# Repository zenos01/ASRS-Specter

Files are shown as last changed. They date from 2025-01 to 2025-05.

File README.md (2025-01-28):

# Fiber Optic FPV System

A **DIY Fiber Optic-enabled FPV video and control system** designed for affordable, high-performance drone operation. This system uses off-the-shelf components to deliver interference-free communication and advanced features at a cost of around **$300**.

## Key Features
- **Fiber Optic Communication**: Reliable and interference-free in challenging environments.
- **Customizable and Open Source**: Fully programmable, allowing for custom OSD elements, unique arming methods, and feature expansion.
- **High-Performance Video**:
  - Supports **1600x900 at 60fps** and **720p at 120fps**.
- **Advanced Capabilities**:
  - Real-time trajectory estimation for precise object dropping or landings.
  - Multi-camera support for enhanced situational awareness.
  - Ground station processing for greater computational power and flexibility.

## About the Project
This project aims to provide an affordable, flexible, and customizable alternative to traditional FPV systems. While still a prototype, it’s open to collaboration and feedback to refine and expand its capabilities.

## Getting Started
The **hardware guide** and **software guide** are currently a work in progress, but the basic setup will be updated soon. Stay tuned for detailed instructions!

## Contributing
Contributions are welcome! You can:
- Report issues via [GitHub Issues](link-to-issues).
- Suggest features or improvements.
- Submit pull requests to help refine the project.

---

Thank you.

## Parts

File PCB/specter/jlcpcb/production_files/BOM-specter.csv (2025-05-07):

Comment | Designator | Footprint | LCSC | Quantity
1K | R17,R19,R23 | R_0402_1005Metric | C11702 | 3
100uF | C14 | CP_EIA-7343-31_Kemet-D | C122321 | 1
10uF | C5,C7 | C_1206_3216Metric_Pad1.33x1.80mm_HandSolder | C13585 | 2
Bus_M.2_Socket_M | J3 | M.2 M Key socket | C1509730 | 1
100n | C1,C17,C2,C23 | C_0402_1005Metric | C1525 | 4
4.7nF | C18 | C_0402_1005Metric | C1538 | 1
10uF | C11,C12,C13,C15,C16,C19,C20,C21,C22,C8 | C_0805_2012Metric | C15850 | 10
SM04B-SRSS-TB_LF__SN_ | J22,J24,J25,J26 | JST_SM04B-SRSS-TB_LF__SN_ | C160404 | 4
1K | R2,R3,R5,R7,R8,R9 | R_0805_2012Metric_Pad1.20x1.40mm_HandSolder | C17513 | 6
SKQGAFE010 | S1 | SW_SKQGAFE010 | C202424 | 1
AP3441SHE-7B | U9 | DFN-8-1EP_2x2mm_P0.5mm_EP1.05x1.75mm | C2070918 | 1
AP2553W6 | U8 | SOT-23-6 | C212302 | 1
2.2uH | L1 | L_Bourns_SRP5030CC | C22404330 | 1
LED RED | D7,D8 | LED_0603_1608Metric | C2290 | 2
LED | D1,D2,D5,D6,D9 | LED_0805_2012Metric_Pad1.15x1.40mm_HandSolder | C2297 | 5
RT9742GGJ5 | U3 | SOT-23-5 | C250547 | 1
100K | 1% | R20 | R_0402_1005Metric | C25741 | 1
10K | 1% | R21 | R_0402_1005Metric | C25744 | 1
15K | R18 | R_0402_1005Metric | C25756 | 1
2.2K 1% | R1,R12,R13,R14,R22 | R_0402_1005Metric | C25879 | 5
ASEK-32.768KHZ-L-R-T | U10 | Crystal_SMD_3225-4Pin_3.2x2.5mm | C2650753 | 1
1uF | C3,C9 | C_0805_2012Metric_Pad1.18x1.45mm_HandSolder | C28323 | 2
LED | D3,D4 | LED_0805_2012Metric_Pad1.15x1.40mm_HandSolder | C34499 | 2
DF40C-100DS-0.4V_51_ | J6,J9 | HIROSE_DF40C-100DS-0.4V_51_ | C3642394 | 2
Micro_SD_Card_Det2 | J2 | SDCARD_MOLEX_503398-1892 | C428492 | 1
100nF | C4,C6 | C_0805_2012Metric_Pad1.18x1.45mm_HandSolder | C49678 | 2
74LVC1G07_copy | U7 | SOT-353_SC-70-5 | C5138996 | 1
USB_C_Receptacle_USB2.0_16P | J1 | USB_C_Receptacle_GCT_USB4105-xx-A_16P_TopMnt_Horizontal | C5187472 | 1
Conn_01x22_Socket | J4,J5 | Hirose_FH12-22S-0.5SH_1x22-1MP_P0.50mm_Horizontal | C597981 | 2
FT232RL | U1,U2 | SSOP-28_5.3x10.2mm_P0.65mm | C8690 | 2
SM06B-SRSS-TB_LF__SN_ | J27,J28,J29,J30 | JST_SM06B-SRSS-TB_LF__SN_ | C9900025724 | 4

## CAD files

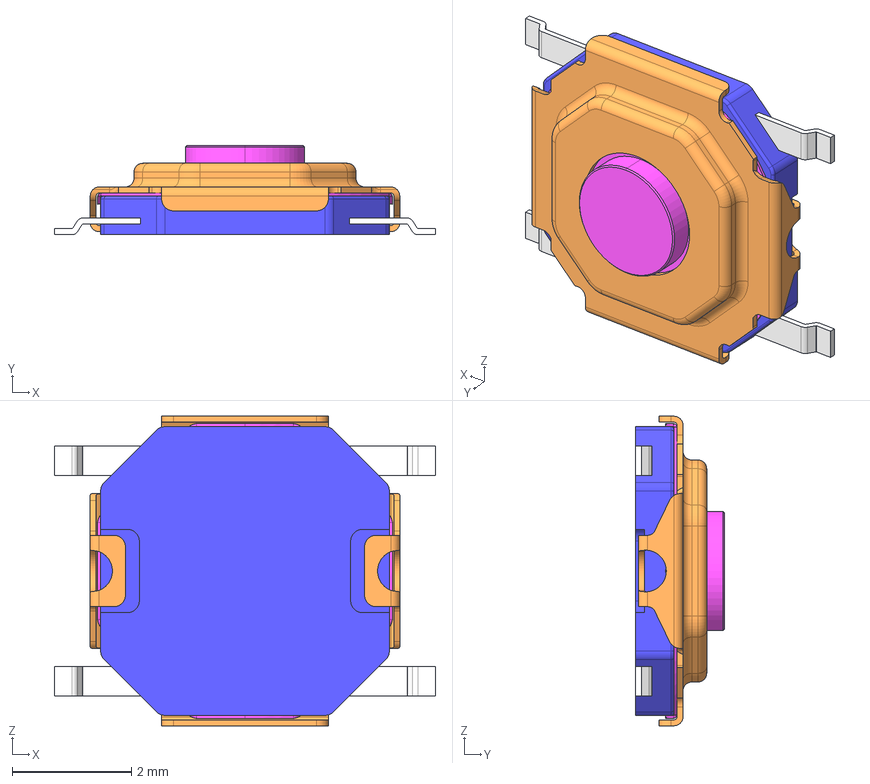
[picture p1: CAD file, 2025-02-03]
PCB/footprints/SKQGAFE010/SKQGAFE010.step
6.40 x 1.50 x 5.20 mm

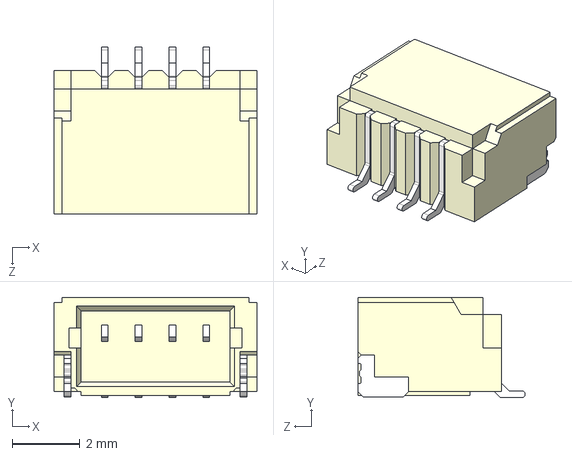
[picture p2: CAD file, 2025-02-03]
PCB/footprints/SM04B-SRSS-TB_LF__SN_/SM04B-SRSS-TB(LF)(SN)--3DModel-STEP-269445.STEP
6.00 x 2.96 x 4.95 mm

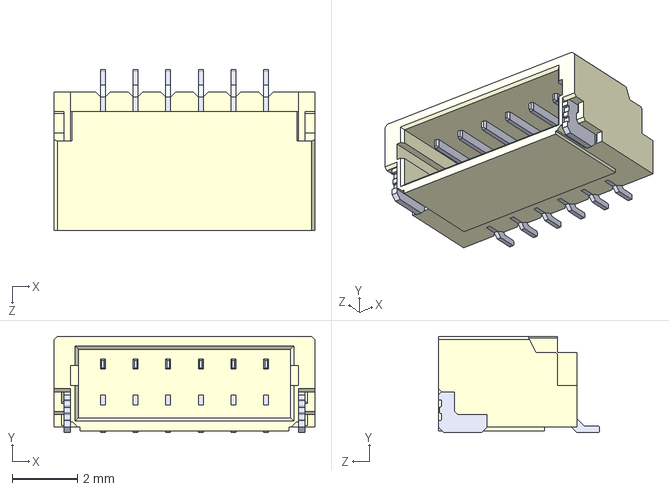
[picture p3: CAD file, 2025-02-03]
PCB/footprints/SM06B-SRSS-TB_LF__SN_/SM06B-SRSS-TB_LF__SN_.step
8.00 x 2.95 x 4.95 mm

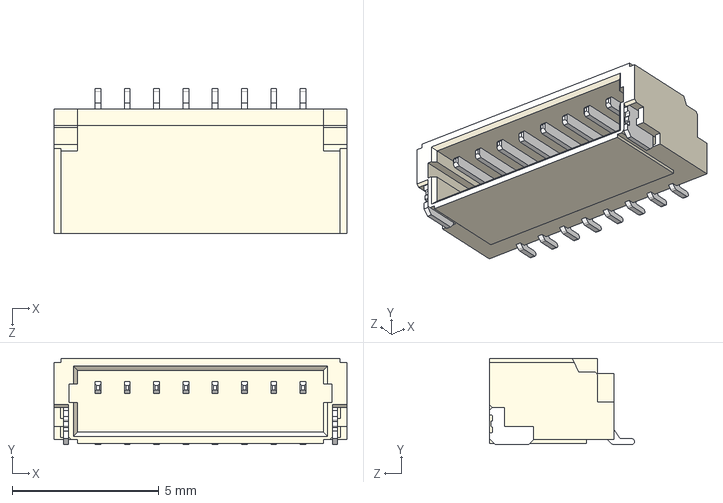
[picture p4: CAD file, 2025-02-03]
PCB/footprints/SM08B-SRSS-TB_LF__SN_/SM08B-SRSS-TB_LF__SN_.step
10.00 x 2.95 x 4.95 mm

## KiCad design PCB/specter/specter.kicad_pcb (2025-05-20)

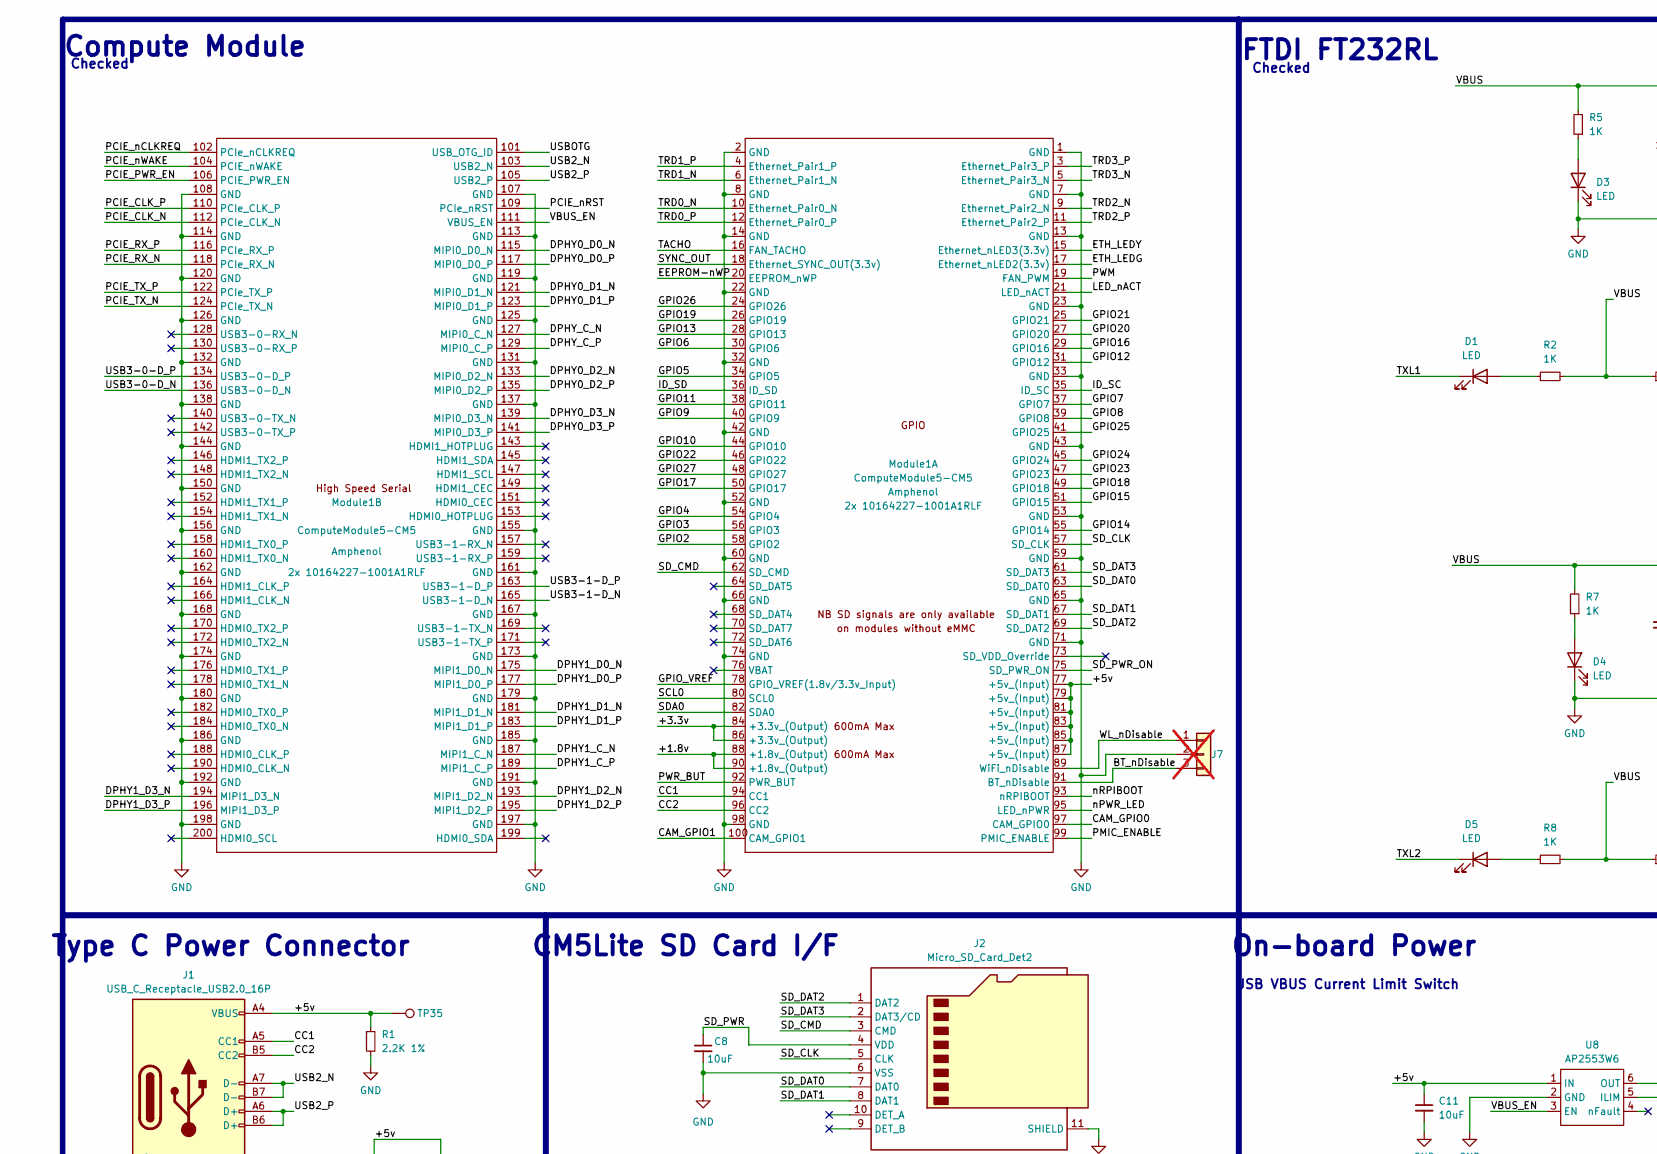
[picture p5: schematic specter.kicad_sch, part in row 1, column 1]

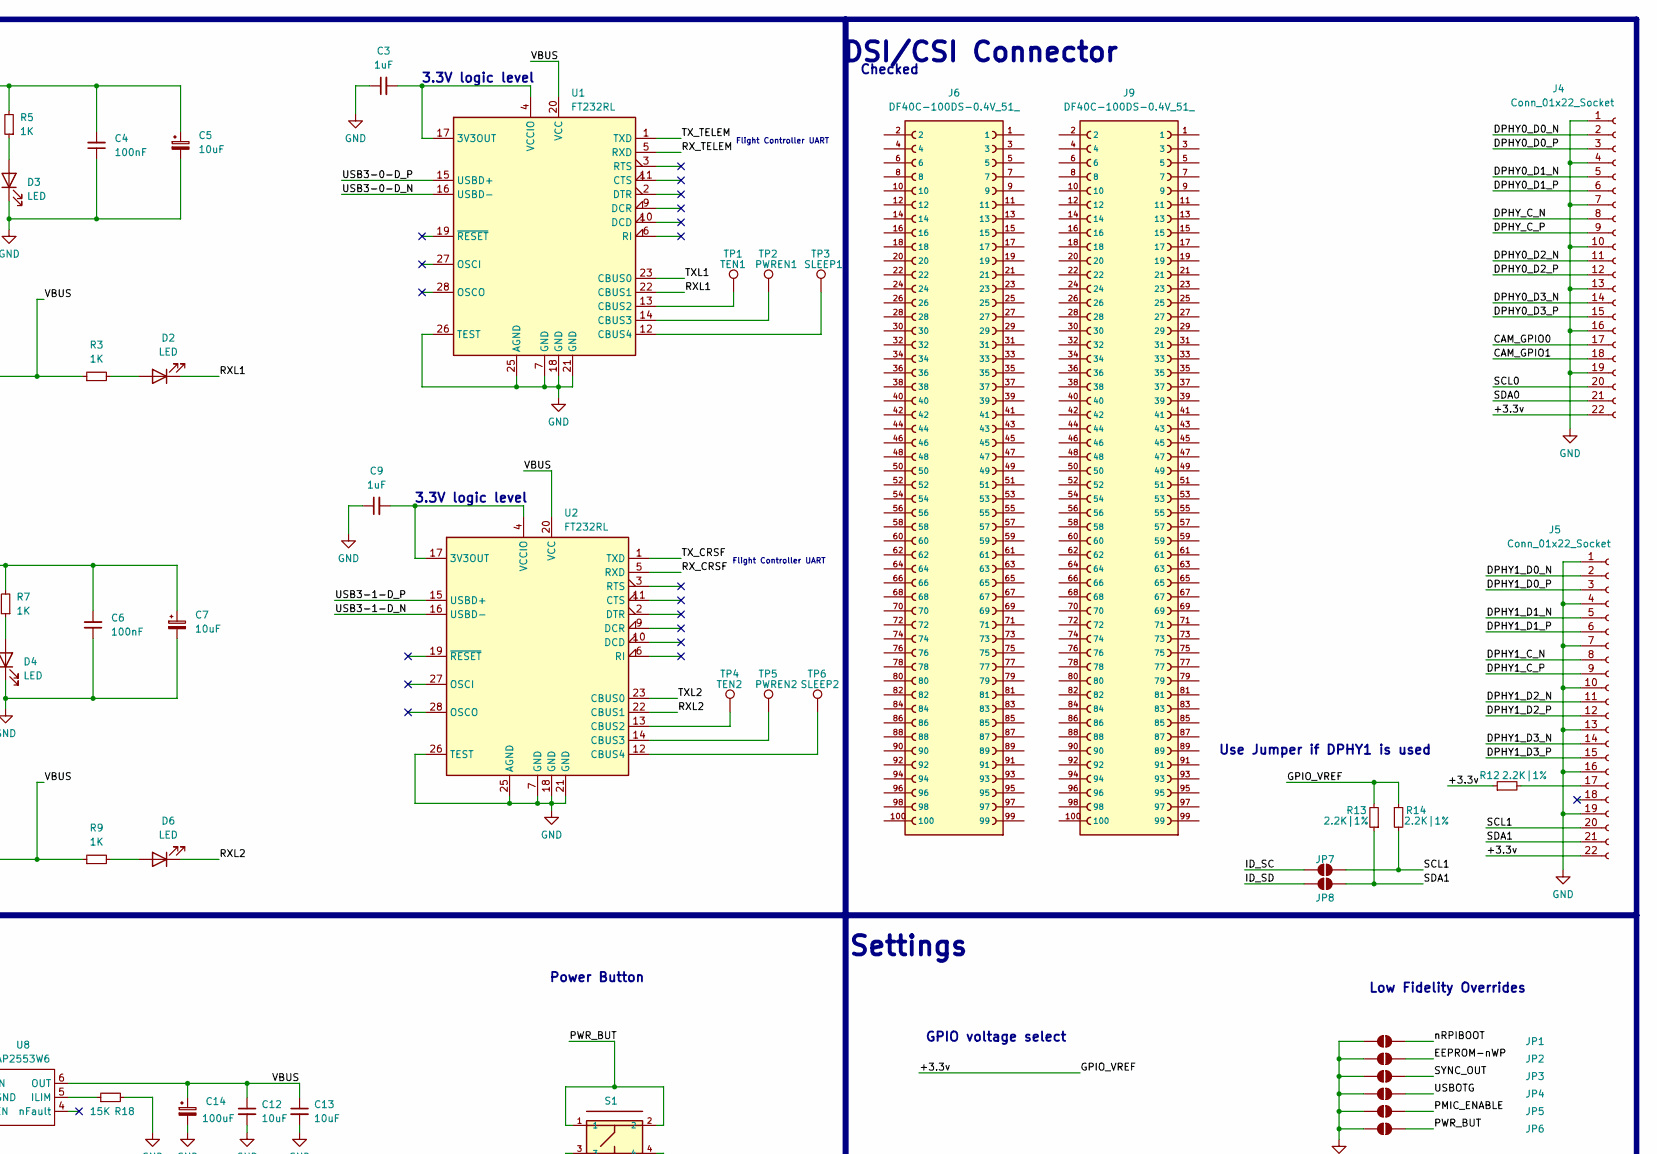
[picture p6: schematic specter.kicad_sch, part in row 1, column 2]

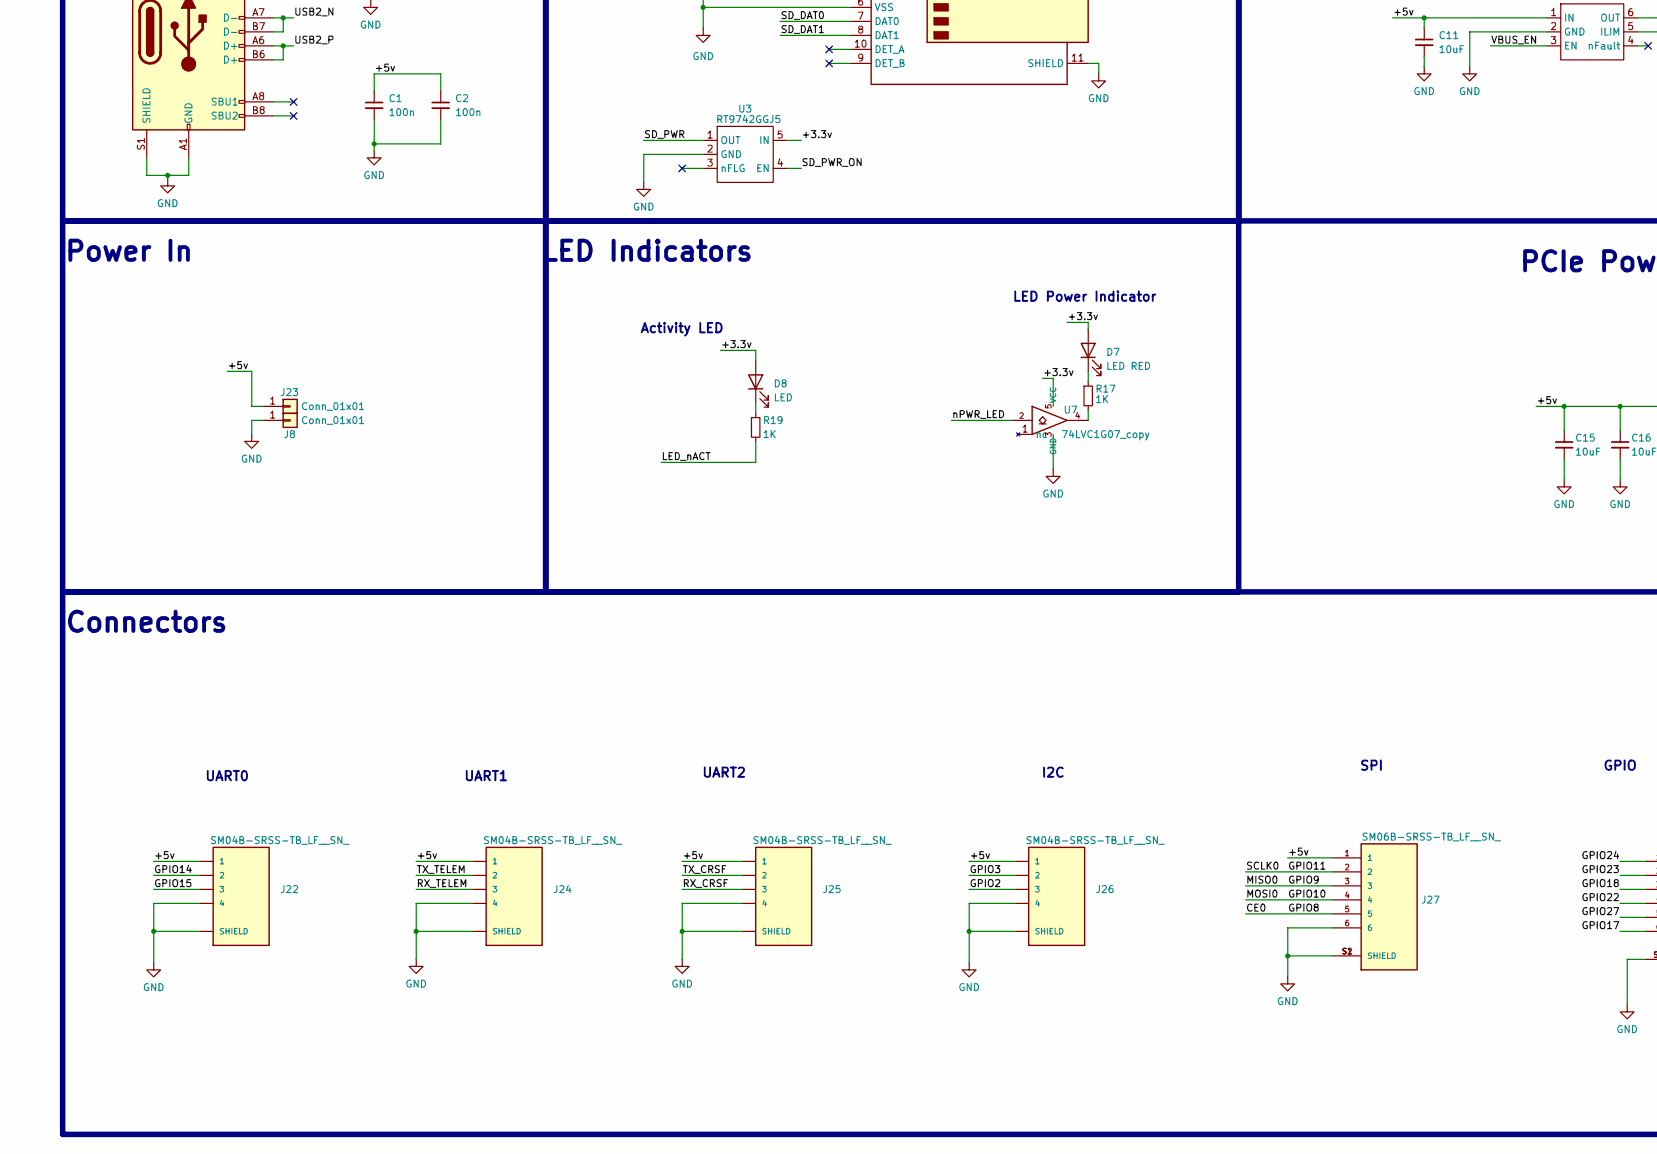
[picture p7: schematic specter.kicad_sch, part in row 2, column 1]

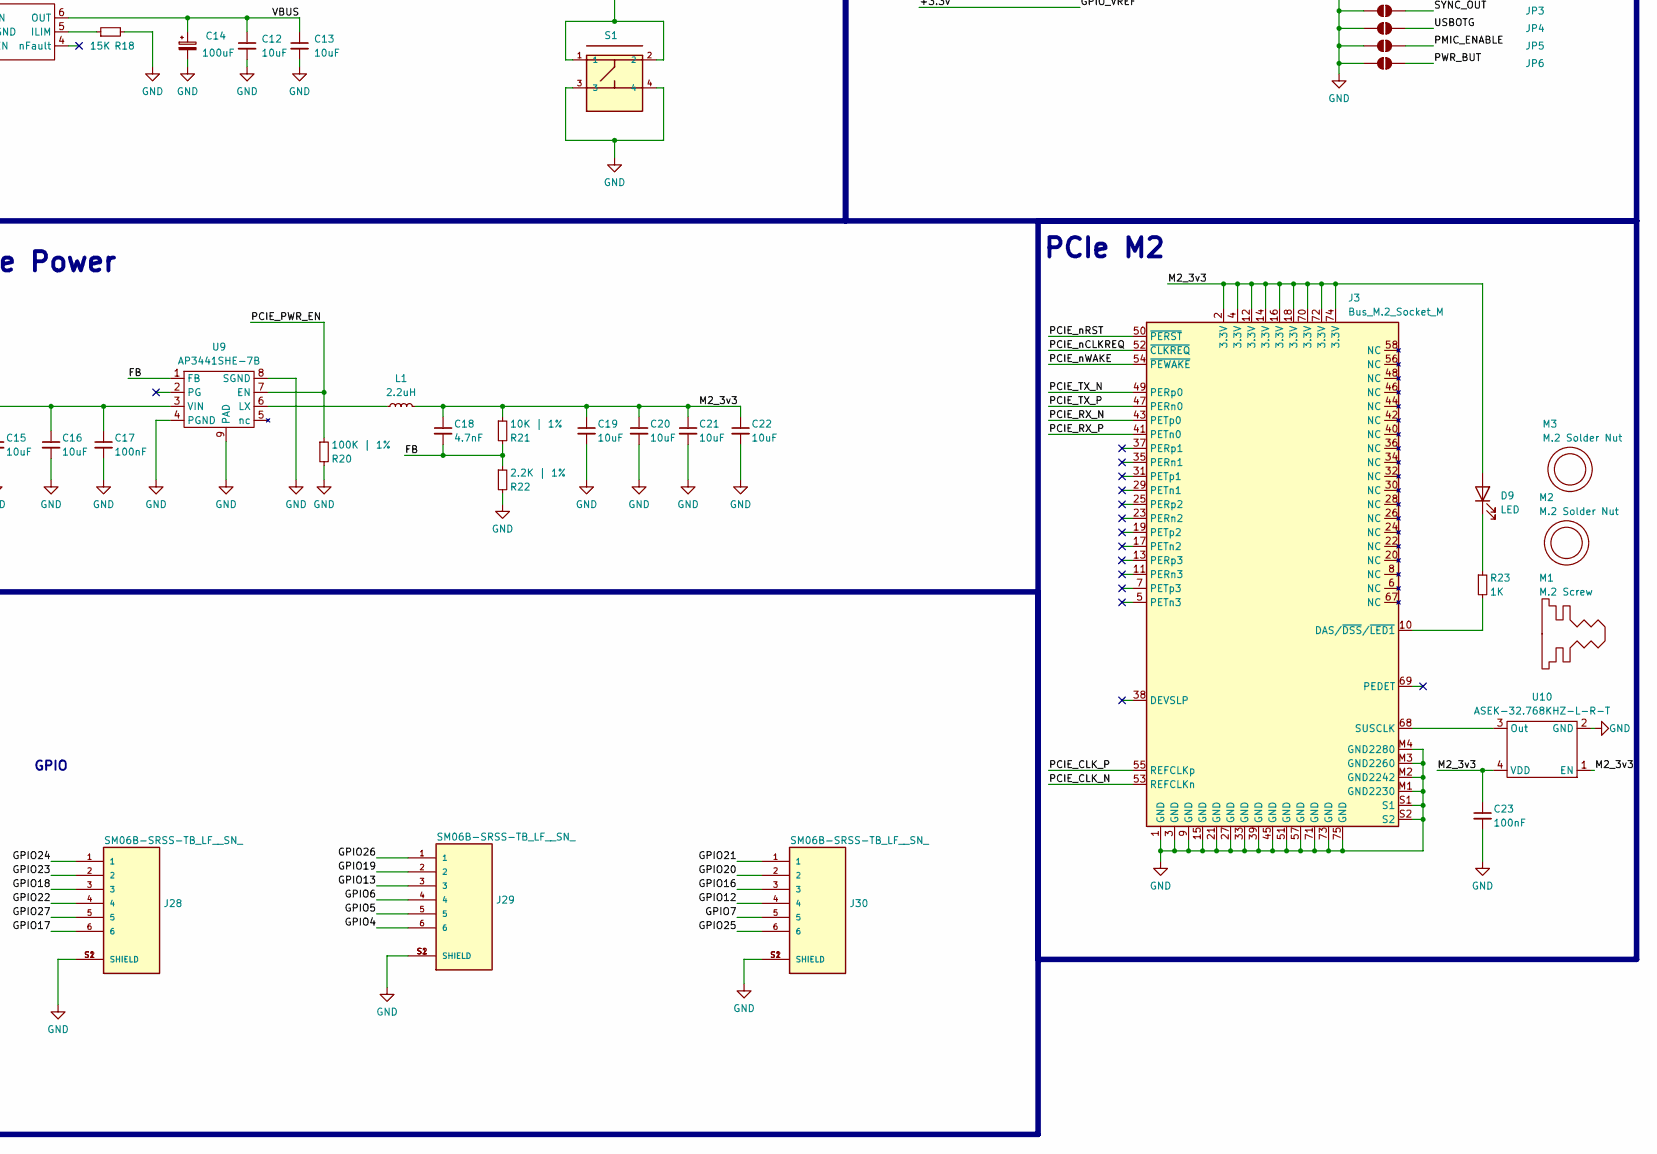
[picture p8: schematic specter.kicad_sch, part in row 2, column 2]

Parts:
C1, C2: 100n; C_0402_1005Metric
C3, C9: 1uF; C_0805_2012Metric_Pad1.18x1.45mm_HandSolder
C4, C6: 100nF; C_0805_2012Metric_Pad1.18x1.45mm_HandSolder
C5, C7: 10uF; C_1206_3216Metric_Pad1.33x1.80mm_HandSolder
C8, C11, C12, C13, C15, C16, C19, C20, C21, C22: 10uF; C_0805_2012Metric
C14: 100uF; CP_EIA-7343-31_Kemet-D
C17, C23: 100nF; C_0402_1005Metric
C18: 4.7nF; C_0402_1005Metric
D1, D2, D3, D4, D5, D6, D9: LED; LED_0805_2012Metric_Pad1.15x1.40mm_HandSolder
D7: LED RED; LED_0603_1608Metric
D8: LED; LED_0603_1608Metric
J1: USB_C_Receptacle_USB2.0_16P; USB_C_Receptacle_GCT_USB4105-xx-A_16P_TopMnt_Horizontal
J2: Micro_SD_Card_Det2; SDCARD_MOLEX_503398-1892
J3: Bus_M.2_Socket_M; M.2 M Key socket
J4, J5: Conn_01x22_Socket; Hirose_FH12-22S-0.5SH_1x22-1MP_P0.50mm_Horizontal
J6, J9: DF40C-100DS-0.4V_51_; HIROSE_DF40C-100DS-0.4V_51_; PARTREV Oct.1.2023
J7: Conn_01x03; SolderJumper-3_P1.3mm_Open_RoundedPad1.0x1.5mm_NumberLabels; not fitted
J8, J23: Conn_01x01; TestPoint_THTPad_4.0x4.0mm_Drill2.0mm
J22, J24, J25, J26: SM04B-SRSS-TB_LF__SN_; JST_SM04B-SRSS-TB_LF__SN_
J27, J28, J29, J30: SM06B-SRSS-TB_LF__SN_; JST_SM06B-SRSS-TB_LF__SN_
JP1, JP2, JP3, JP4, JP5, JP6: SolderJumper_2_Open; SolderJumper-2_P1.3mm_Open_Pad1.0x1.5mm
JP7, JP8: SolderJumper_2_Open; SolderJumper-2_P1.3mm_Open_RoundedPad1.0x1.5mm
L1: 2.2uH; L_Bourns_SRP5030CC
M1: M.2 Screw
M2, M3: M.2 Solder Nut
Module1: ComputeModule5-CM5; Raspberry-Pi-5-Compute-Module
R1: 2.2K 1%; R_0402_1005Metric
R2, R3, R5, R7, R8, R9: 1K; R_0805_2012Metric_Pad1.20x1.40mm_HandSolder
R12, R13, R14: 2.2K|1%; R_0402_1005Metric
R17, R19, R23: 1K; R_0402_1005Metric
R18: 15K; R_0402_1005Metric
R20: 100K | 1%; R_0402_1005Metric
R21: 10K | 1%; R_0402_1005Metric
R22: 2.2K | 1%; R_0402_1005Metric
S1: SKQGAFE010; SW_SKQGAFE010; PART_REV B1
TP1: TEN1; TestPoint_Pad_D1.0mm
TP2: PWREN1; TestPoint_Pad_D1.0mm
TP3: SLEEP1; TestPoint_Pad_D1.0mm
TP4: TEN2; TestPoint_Pad_D1.0mm
TP5: PWREN2; TestPoint_Pad_D1.0mm
TP6: SLEEP2; TestPoint_Pad_D1.0mm
TP35: TestPoint; TestPoint_Pad_D1.0mm
U1, U2: FT232RL; SSOP-28_5.3x10.2mm_P0.65mm
U3: RT9742GGJ5; SOT-23-5
U7: 74LVC1G07_copy; SOT-353_SC-70-5
U8: AP2553W6; SOT-23-6
U9: AP3441SHE-7B; DFN-8-1EP_2x2mm_P0.5mm_EP1.05x1.75mm
U10: ASEK-32.768KHZ-L-R-T; Crystal_SMD_3225-4Pin_3.2x2.5mm

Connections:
/+1.8v: Module1.88 (+1.8v_(Output)), Module1.90 (+1.8v_(Output))
/+3.3v: D7.2 (A), D8.2 (A), J4.22, J5.22, Module1.78 (GPIO_VREF(1.8v/3.3v_Input)), Module1.84 (+3.3v_(Output)), Module1.86 (+3.3v_(Output)), R12.1, R13.2, R14.1, U3.5 (IN), U7.5 (VCC); also elsewhere on the board
/+5v: C1.1, C2.1, C11.1, C15.1, C16.1, C17.1, J1.A4 (VBUS), J1.A9 (VBUS), J1.B4 (VBUS), J1.B9 (VBUS), J22.1, J23.1, J24.1, J25.1, J26.1, J27.1, Module1.77 (+5v_(Input)), Module1.79 (+5v_(Input)), Module1.81 (+5v_(Input)), Module1.83 (+5v_(Input)), Module1.85 (+5v_(Input)), Module1.87 (+5v_(Input)), R1.1, TP35.1, U8.1 (IN), U9.3 (VIN)
/BT_nDisable: J7.3, Module1.91 (BT_nDisable)
/CAM_GPIO0: J4.17, Module1.97 (CAM_GPIO0)
/CAM_GPIO1: J4.18, Module1.100 (CAM_GPIO1)
/CC1: J1.A5 (CC1), Module1.94 (CC1)
/CC2: J1.B5 (CC2), Module1.96 (CC2)
/CE0: J27.5, Module1.39 (GPIO8)
/DPHY0_D0_N: J4.2, Module1.115 (MIPI0_D0_N)
/DPHY0_D0_P: J4.3, Module1.117 (MIPI0_D0_P)
/DPHY0_D1_N: J4.5, Module1.121 (MIPI0_D1_N)
/DPHY0_D1_P: J4.6, Module1.123 (MIPI0_D1_P)
/DPHY0_D2_N: J4.11, Module1.133 (MIPI0_D2_N)
/DPHY0_D2_P: J4.12, Module1.135 (MIPI0_D2_P)
/DPHY0_D3_N: J4.14, Module1.139 (MIPI0_D3_N)
/DPHY0_D3_P: J4.15, Module1.141 (MIPI0_D3_P)
/DPHY1_C_N: J5.8, Module1.187 (MIPI1_C_N)
/DPHY1_C_P: J5.9, Module1.189 (MIPI1_C_P)
/DPHY1_D0_N: J5.2, Module1.175 (MIPI1_D0_N)
/DPHY1_D0_P: J5.3, Module1.177 (MIPI1_D0_P)
/DPHY1_D1_N: J5.5, Module1.181 (MIPI1_D1_N)
/DPHY1_D1_P: J5.6, Module1.183 (MIPI1_D1_P)
/DPHY1_D2_N: J5.11, Module1.193 (MIPI1_D2_N)
/DPHY1_D2_P: J5.12, Module1.195 (MIPI1_D2_P)
/DPHY1_D3_N: J5.14, Module1.194 (MIPI1_D3_N)
/DPHY1_D3_P: J5.15, Module1.196 (MIPI1_D3_P)
/DPHY_C_N: J4.8, Module1.127 (MIPI0_C_N)
/DPHY_C_P: J4.9, Module1.129 (MIPI0_C_P)
/EEPROM-nWP: JP2.2 (B), Module1.20 (EEPROM_nWP)
/ETH_LEDG: Module1.17 (Ethernet_nLED2(3.3v))
/ETH_LEDY: Module1.15 (Ethernet_nLED3(3.3v))
/FB: C18.2, R21.2, R22.1, U9.1 (FB)
/GPIO2: J26.3, Module1.58 (GPIO2)
/GPIO3: J26.2, Module1.56 (GPIO3)
/GPIO4: J29.6, Module1.54 (GPIO4)
/GPIO5: J29.5, Module1.34 (GPIO5)
/GPIO6: J29.4, Module1.30 (GPIO6)
/GPIO7: J30.5, Module1.37 (GPIO7)
/GPIO9: J27.3, Module1.40 (GPIO9)
/GPIO10: J27.4, Module1.44 (GPIO10)
/GPIO11: J27.2, Module1.38 (GPIO11)
/GPIO12: J30.4, Module1.31 (GPIO12)
/GPIO13: J29.3, Module1.28 (GPIO13)
/GPIO14: J22.2, Module1.55 (GPIO14)
/GPIO15: J22.3, Module1.51 (GPIO15)
/GPIO16: J30.3, Module1.29 (GPIO16)
/GPIO17: J28.6, Module1.50 (GPIO17)
/GPIO18: J28.3, Module1.49 (GPIO18)
/GPIO19: J29.2, Module1.26 (GPIO19)
/GPIO20: J30.2, Module1.27 (GPIO20)
/GPIO21: J30.1, Module1.25 (GPIO21)
/GPIO22: J28.4, Module1.46 (GPIO22)
/GPIO23: J28.2, Module1.47 (GPIO23)
/GPIO24: J28.1, Module1.45 (GPIO24)
/GPIO25: J30.6, Module1.41 (GPIO25)
/GPIO26: J29.1, Module1.24 (GPIO26)
/GPIO27: J28.5, Module1.48 (GPIO27)
/ID_SC: JP7.1 (A), Module1.35 (ID_SC)
/ID_SD: JP8.1 (A), Module1.36 (ID_SD)
/LED_nACT: Module1.21 (LED_nACT), R19.2
/M2_3v3: C18.1, C19.1, C20.1, C21.1, C22.1, C23.1, D9.2 (A), J3.2 (3.3V), J3.4 (3.3V), J3.12 (3.3V), J3.14 (3.3V), J3.16 (3.3V), J3.18 (3.3V), J3.70 (3.3V), J3.72 (3.3V), J3.74 (3.3V), L1.2, R21.1, U10.1 (EN), U10.4 (VDD)
/PCIE_CLK_N: J3.53 (REFCLKn), Module1.112 (PCIe_CLK_N)
/PCIE_CLK_P: J3.55 (REFCLKp), Module1.110 (PCIe_CLK_P)
/PCIE_PWR_EN: Module1.106 (PCIE_PWR_EN), R20.1, U9.7 (EN)
/PCIE_RX_N: J3.43 (PETp0), Module1.118 (PCIe_RX_N)
/PCIE_RX_P: J3.41 (PETn0), Module1.116 (PCIe_RX_P)
/PCIE_TX_N: J3.49 (PERp0), Module1.124 (PCIe_TX_N)
/PCIE_TX_P: J3.47 (PERn0), Module1.122 (PCIe_TX_P)
/PCIE_nCLKREQ: J3.52 (~CLKREQ), Module1.102 (PCIe_nCLKREQ)
/PCIE_nRST: J3.50 (~PERST), Module1.109 (PCIe_nRST)
/PCIE_nWAKE: J3.54 (~PEWAKE), Module1.104 (PCIE_nWAKE)
/PMIC_ENABLE: JP5.2 (B), Module1.99 (PMIC_ENABLE)
/PWM: Module1.19 (FAN_PWM)
/PWR_BUT: JP6.2 (B), Module1.92 (PWR_BUT), S1.1, S1.2
/RXL1: D2.1 (K), U1.22 (CBUS1)
/RXL2: D6.1 (K), U2.22 (CBUS1)
/RX_CRSF: J25.3, U2.5 (RXD)
/RX_TELEM: J24.3, U1.5 (RXD)
/SCL0: J4.20, Module1.80 (SCL0)
/SCL1: J5.20, JP7.2 (B), R14.2
/SDA0: J4.21, Module1.82 (SDA0)
/SDA1: J5.21, JP8.2 (B), R13.1
/SD_CLK: J2.5 (CLK), Module1.57 (SD_CLK)
/SD_CMD: J2.3 (CMD), Module1.62 (SD_CMD)
/SD_DAT0: J2.7 (DAT0), Module1.63 (SD_DAT0)
/SD_DAT1: J2.8 (DAT1), Module1.67 (SD_DAT1)
/SD_DAT2: J2.1 (DAT2), Module1.69 (SD_DAT2)
/SD_DAT3: J2.2 (DAT3/CD), Module1.61 (SD_DAT3)
/SD_PWR: C8.1, J2.4 (VDD), U3.1 (OUT)
/SD_PWR_ON: Module1.75 (SD_PWR_ON), U3.4 (EN)
/SYNC_OUT: JP3.2 (B), Module1.18 (Ethernet_SYNC_OUT(3.3v))
/TACHO: Module1.16 (FAN_TACHO)
/TRD0_N: Module1.10 (Ethernet_Pair0_N)
/TRD0_P: Module1.12 (Ethernet_Pair0_P)
/TRD1_N: Module1.6 (Ethernet_Pair1_N)
/TRD1_P: Module1.4 (Ethernet_Pair1_P)
/TRD2_N: Module1.9 (Ethernet_Pair2_N)
/TRD2_P: Module1.11 (Ethernet_Pair2_P)
/TRD3_N: Module1.5 (Ethernet_Pair3_N)
/TRD3_P: Module1.3 (Ethernet_Pair3_P)
/TXL1: D1.1 (K), U1.23 (CBUS0)
/TXL2: D5.1 (K), U2.23 (CBUS0)
/TX_CRSF: J25.2, U2.1 (TXD)
/TX_TELEM: J24.2, U1.1 (TXD)
/USB2_N: J1.A7 (D-), J1.B7 (D-), Module1.103 (USB2_N)
/USB2_P: J1.A6 (D+), J1.B6 (D+), Module1.105 (USB2_P)
/USB3-0-D_N: Module1.136 (USB3-0-D_N), U1.16 (USBD-)
/USB3-0-D_P: Module1.134 (USB3-0-D_P), U1.15 (USBD+)
/USB3-1-D_N: Module1.165 (USB3-1-D_N), U2.16 (USBD-)
/USB3-1-D_P: Module1.163 (USB3-1-D_P), U2.15 (USBD+)
/USBOTG: JP4.2 (B), Module1.101 (USB_OTG_ID)
/VBUS: C4.2, C5.1, C6.2, C7.1, C12.1, C13.1, C14.1, R2.2, R3.1, R5.2, R7.2, R8.2, R9.1, U1.20 (VCC), U2.20 (VCC), U8.6 (OUT)
/VBUS_EN: Module1.111 (VBUS_EN), U8.3 (EN)
/WL_nDisable: J7.1, Module1.89 (WiFi_nDisable)
/nPWR_LED: Module1.95 (LED_nPWR), U7.2
/nRPIBOOT: JP1.2 (B), Module1.93 (nRPIBOOT)
GND: C1.2, C2.2, C3.1, C4.1, C5.2, C6.1, C7.2, C8.2, C9.1, C11.2, C12.2, C13.2, C14.2, C15.2, C16.2, C17.2, C19.2, C20.2, C21.2, C22.2, C23.2, D3.1 (K), D4.1 (K), J1.A1 (GND), J1.A12 (GND), J1.B1 (GND), J1.B12 (GND), J1.S1 (SHIELD), J2.6 (VSS), J2.11 (SHIELD), J3.1 (GND), J3.3 (GND), J3.9 (GND), J3.15 (GND), J3.21 (GND), J3.27 (GND), J3.33 (GND), J3.39 (GND), J3.45 (GND), J3.51 (GND), J3.57 (GND), J3.71 (GND), J3.73 (GND), J3.75 (GND), J3.M1 (GND2230), J3.M2 (GND2242), J3.M3 (GND2260), J3.M4 (GND2280), J3.S1, J3.S2, J4.1, J4.4, J4.7, J4.10, J4.13, J4.16, J4.19, J5.1, J5.4, J5.7, J5.10, J5.13, J5.16, J5.19, J7.2, J8.1, J22.4, J22.S1 (SHIELD), J22.S2 (SHIELD), J24.4, J24.S1 (SHIELD), J24.S2 (SHIELD), J25.4, J25.S1 (SHIELD), J25.S2 (SHIELD), J26.4, J26.S1 (SHIELD), J26.S2 (SHIELD), J27.6, J27.S1 (SHIELD), J27.S2 (SHIELD), J28.S1 (SHIELD), J28.S2 (SHIELD), J29.S1 (SHIELD), J29.S2 (SHIELD), J30.S1 (SHIELD), J30.S2 (SHIELD), JP1.1 (A), JP2.1 (A), JP3.1 (A), JP4.1 (A), JP5.1 (A), JP6.1 (A), Module1.1 (GND), Module1.2 (GND), Module1.7 (GND), Module1.8 (GND), Module1.13 (GND), Module1.14 (GND), Module1.22 (GND), Module1.23 (GND), Module1.32 (GND), Module1.33 (GND), Module1.42 (GND), Module1.43 (GND), Module1.52 (GND), Module1.53 (GND), Module1.59 (GND), Module1.60 (GND), Module1.65 (GND), Module1.66 (GND), Module1.71 (GND), Module1.74 (GND), Module1.98 (GND), Module1.107 (GND), Module1.108 (GND), Module1.113 (GND), Module1.114 (GND), Module1.119 (GND), Module1.120 (GND), Module1.125 (GND), Module1.126 (GND), Module1.131 (GND), Module1.132 (GND), Module1.137 (GND), Module1.138 (GND), Module1.144 (GND), Module1.150 (GND), Module1.155 (GND), Module1.156 (GND), Module1.161 (GND), Module1.162 (GND), Module1.167 (GND), Module1.168 (GND), Module1.173 (GND), Module1.174 (GND), Module1.179 (GND), Module1.180 (GND), Module1.185 (GND), Module1.186 (GND), Module1.191 (GND), Module1.192 (GND), Module1.197 (GND), Module1.198 (GND), R1.2, R18.2, R20.2, R22.2, S1.3, S1.4, U1.7 (GND), U1.18 (GND), U1.21 (GND), U1.25 (AGND), U1.26 (TEST), U2.7 (GND), U2.18 (GND), U2.21 (GND), U2.25 (AGND), U2.26 (TEST), U3.2 (GND), U7.3 (GND), U8.2 (GND), U9.4 (PGND), U9.8 (SGND), U9.9 (PAD), U10.2 (GND)
unnamed: D1.2 (A), R2.1
unnamed: D2.2 (A), R3.2
unnamed: D3.2 (A), R5.1
unnamed: D4.2 (A), R7.1
unnamed: D5.2 (A), R8.1
unnamed: D6.2 (A), R9.2
unnamed: D7.1 (K), R17.1
unnamed: D8.1 (K), R19.1
unnamed: D9.1 (K), R23.1
unnamed: J3.10 (DAS/~DSS/~LED1), R23.2
unnamed: J3.68 (SUSCLK), U10.3 (Out)
unnamed: J5.17, R12.2
unnamed: R17.2, U7.4
unnamed: C3.2, U1.4 (VCCIO), U1.17 (3V3OUT)
unnamed: TP1.1, U1.13 (CBUS2)
unnamed: TP2.1, U1.14 (CBUS3)
unnamed: TP3.1, U1.12 (CBUS4)
unnamed: C9.2, U2.4 (VCCIO), U2.17 (3V3OUT)
unnamed: TP4.1, U2.13 (CBUS2)
unnamed: TP5.1, U2.14 (CBUS3)
unnamed: TP6.1, U2.12 (CBUS4)
unnamed: R18.1, U8.5 (ILIM)
unnamed: L1.1, U9.6 (LX)

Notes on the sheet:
Checked
3.3V logic level
Low Fidelity Overrides
PCIe M2
PCIe Power
SPI
UART2
Activity LED
UART0
GPIO
LED Indicators
Type C Power Connector
I2C
Flight Controller UART
GPIO voltage select
UART1
Connectors
Settings
FTDI FT232RL
Use Jumper if DPHY1 is used
CM5Lite SD Card I/F
Power Button
LED Power Indicator
Compute Module
Power In
On-board Power
USB VBUS Current Limit Switch
DSI/CSI Connector

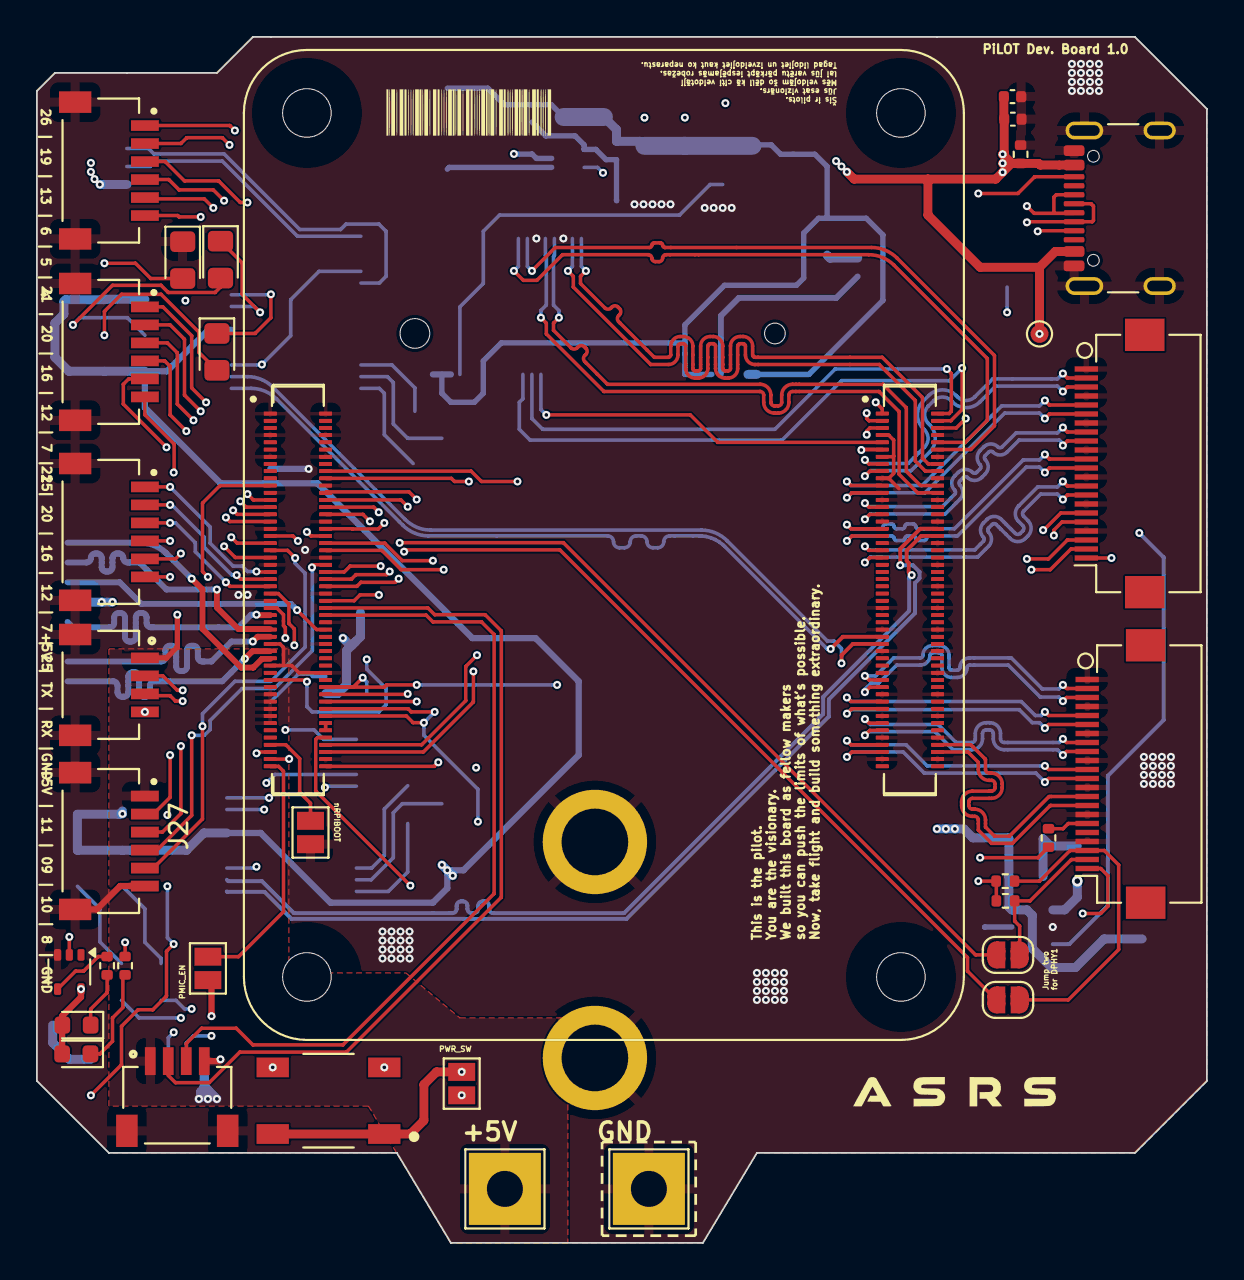
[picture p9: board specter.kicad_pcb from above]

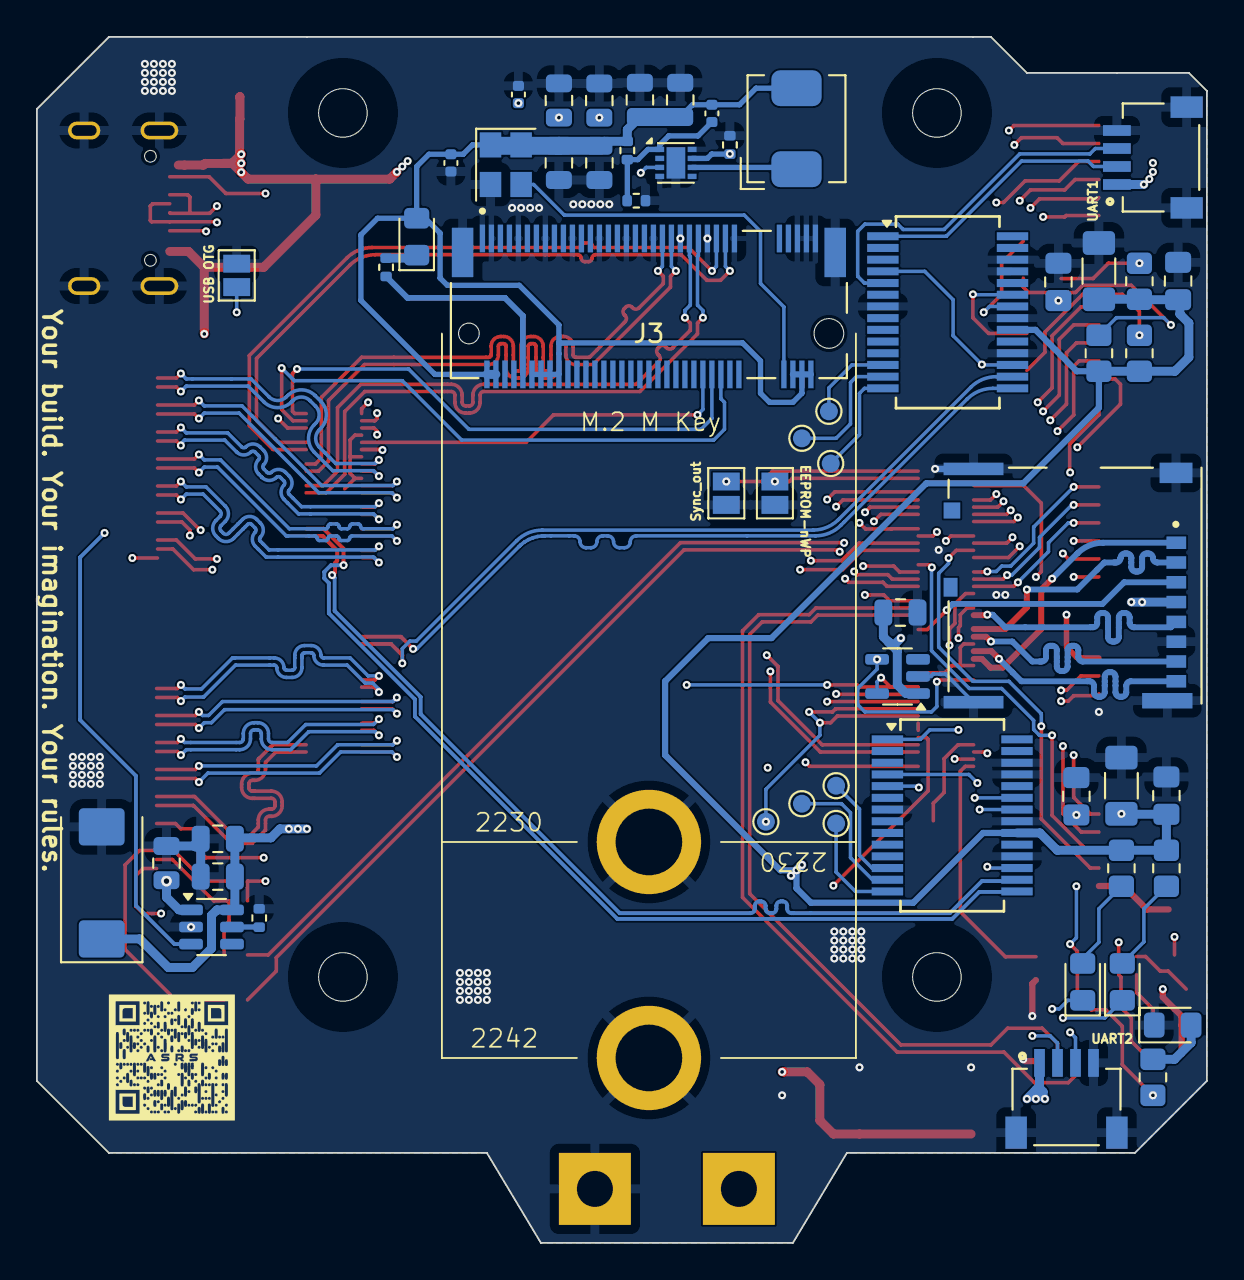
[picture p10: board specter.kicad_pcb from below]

Board: 4 copper layers, 65.0 x 67.0 mm, 91 parts (56 on the bottom side), 127 nets.

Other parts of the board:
TP33: TestPoint; TestPoint_Pad_D1.0mm

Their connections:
/+3.3v: TP33.1; also elsewhere on the board

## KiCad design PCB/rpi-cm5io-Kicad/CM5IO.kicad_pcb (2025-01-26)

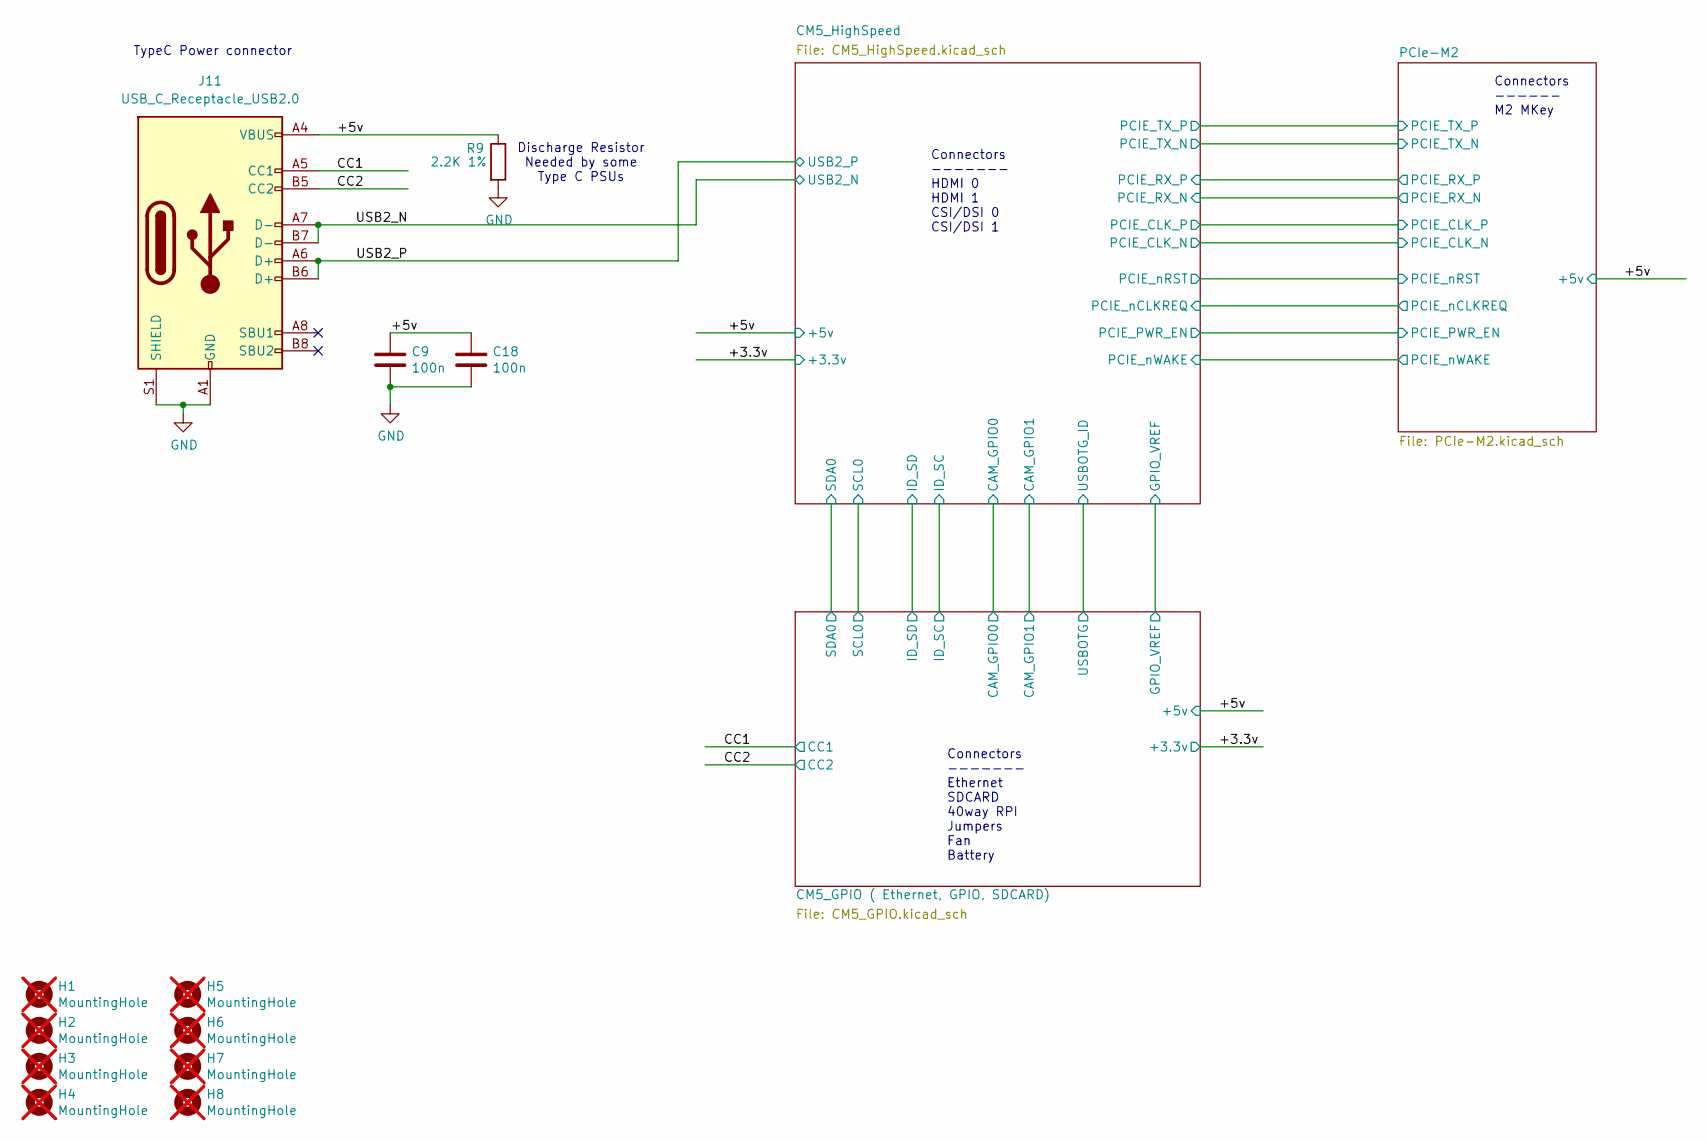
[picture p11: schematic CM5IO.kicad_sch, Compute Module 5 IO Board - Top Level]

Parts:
C9, C18: 100n; C_0402_1005Metric; Part Description 0.1uF 10% 16V Ceramic Capacitor X7R 040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
H1, H2, H3, H4, H5, H6, H7, H8: MountingHole; MountingHole_2.7mm_M2.5_DIN965; Part Description M2.5 mounting hole; not fitted
J11: USB_C_Receptacle_USB2.0; USB_C_Receptacle_GCT_USB4105-xx-A_16P_TopMnt_Horizontal; Part Description USBC USB2 data and power connector
R9: 2.2K 1%; R_0402_1005Metric; Part Description Resistor 2.2K M1005 1% 63mW

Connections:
/+5v: C9.1, C18.1, J11.A4 (VBUS), J11.A9 (VBUS), J11.B4 (VBUS), J11.B9 (VBUS), R9.1; also elsewhere on the board
/CC1: J11.A5 (CC1); also elsewhere on the board
/CC2: J11.B5 (CC2); also elsewhere on the board
/USB2_N: J11.A7 (D-), J11.B7 (D-); also elsewhere on the board
/USB2_P: J11.A6 (D+), J11.B6 (D+); also elsewhere on the board
GND: C9.2, C18.2, J11.A1 (GND), J11.A12 (GND), J11.B1 (GND), J11.B12 (GND), J11.S1 (SHIELD), R9.2; also elsewhere on the board

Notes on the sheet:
Connectors ------- Ethernet SDCARD 40way RPI Jumpers Fan Battery
Connectors ------ M2 MKey
Discharge Resistor Needed by some Type C PSUs
TypeC Power connector
Connectors ------- HDMI 0 HDMI 1 CSI/DSI 0 CSI/DSI 1

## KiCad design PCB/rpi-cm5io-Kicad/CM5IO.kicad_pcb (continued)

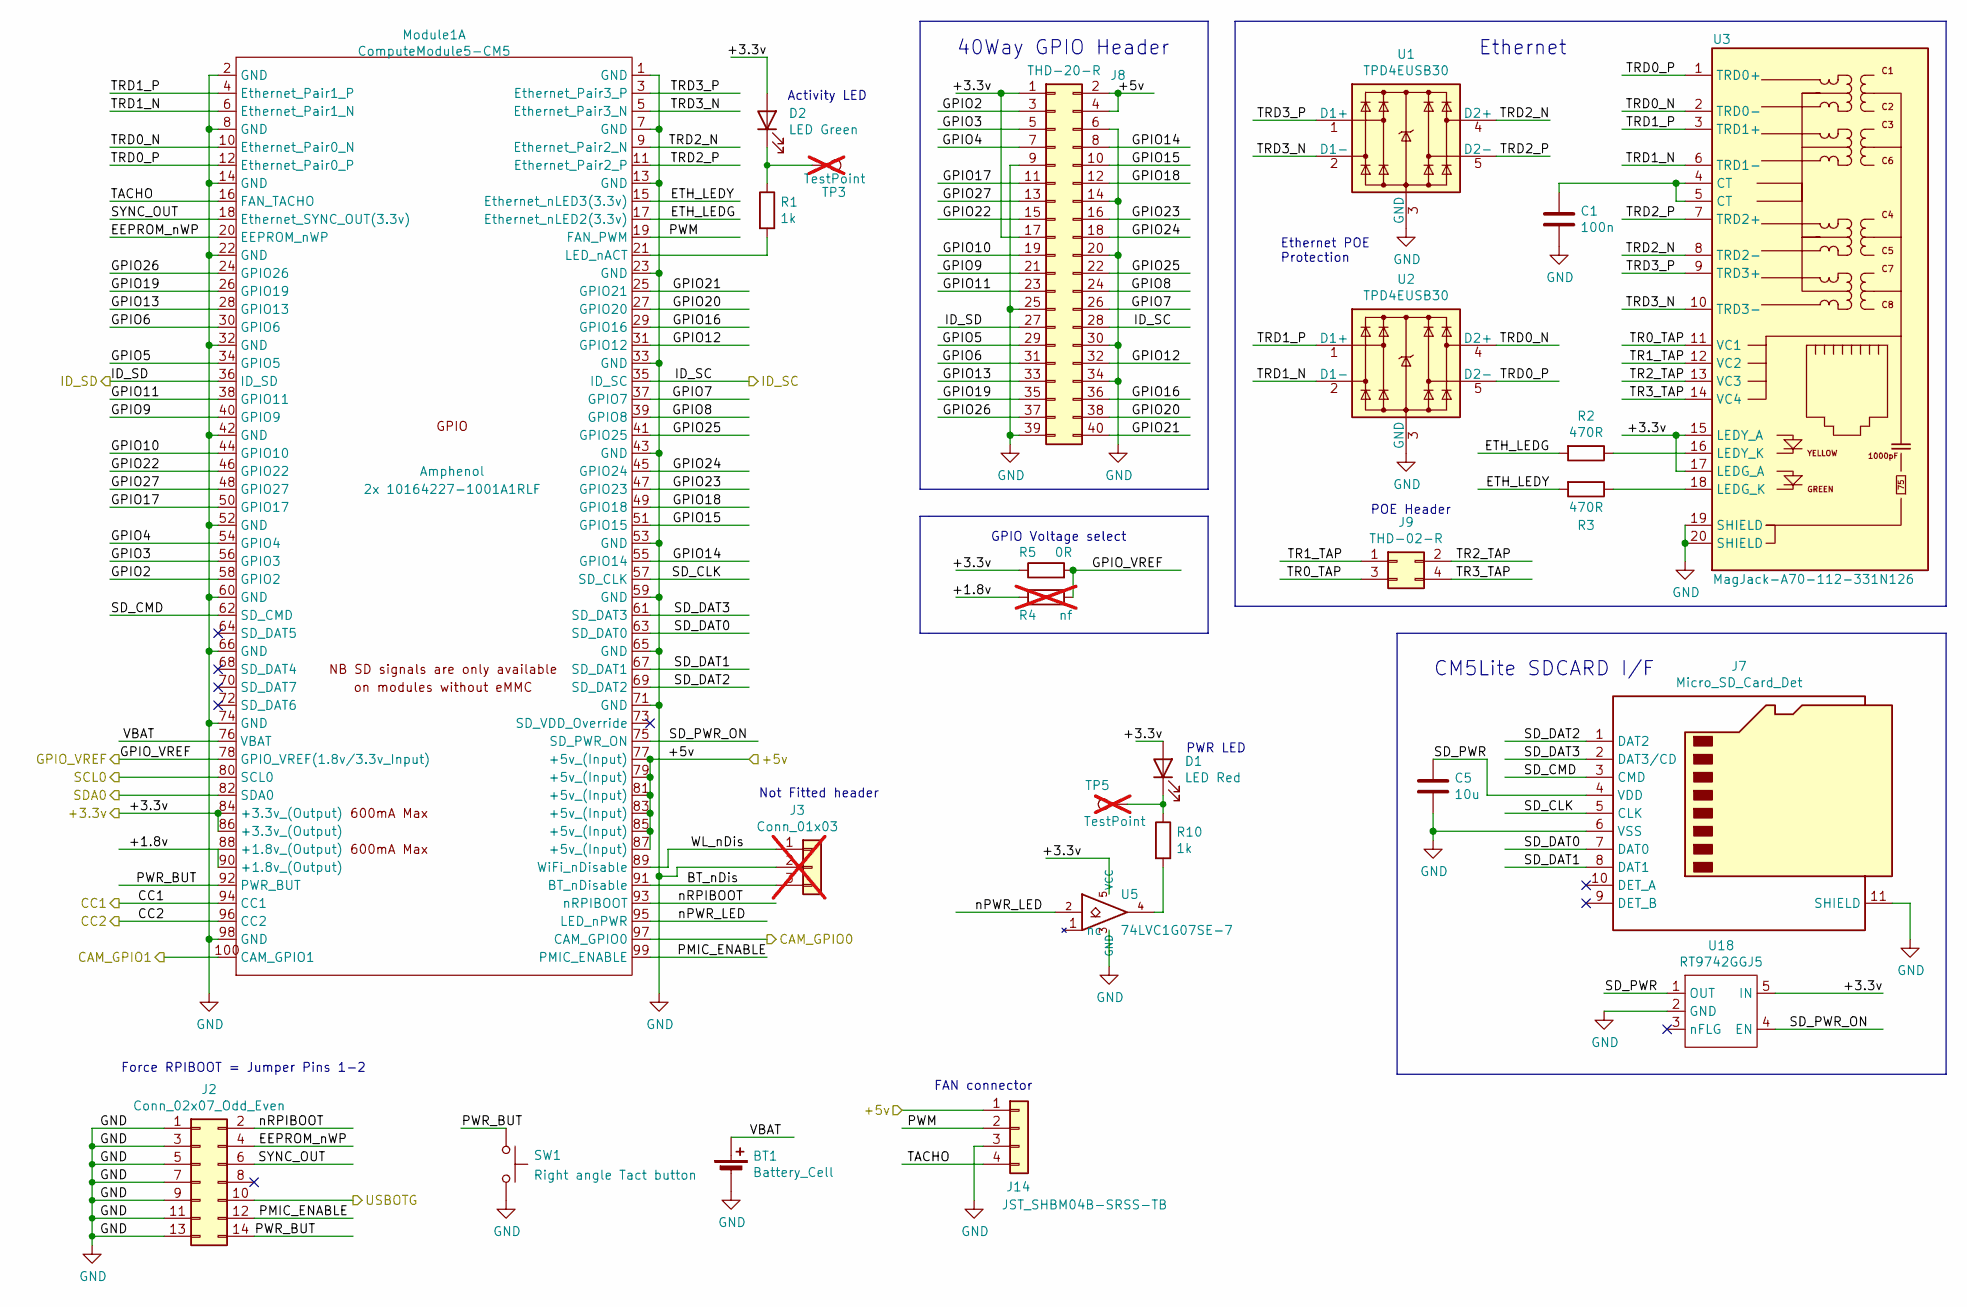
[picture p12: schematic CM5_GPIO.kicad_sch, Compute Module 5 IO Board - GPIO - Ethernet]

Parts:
BT1: Battery_Cell; BatteryHolder_Keystone_3034_1x20mm; Part Description Battery Retainer Coin, 20.0mm 1 Cell SM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
C1: 100n; C_0402_1005Metric; Part Description 0.1uF 10% 16V Ceramic Capacitor X7R 040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
C5: 10u; C_0805_2012Metric; Part Description 10uF 10% 10V Ceramic Capacitor X7R 0805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
D1: LED Red; LED_0603_1608Metric; Part Description Red 620nm LED Indication - Discrete 2.2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
D2: LED Green; LED_0603_1608Metric; Part Description Green 572nm LED Indication - Discrete 2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
J2: Conn_02x07_Odd_Even; PinHeader_2x07_P2.54mm_Vertical; Part Description PinHeader_2x07_P2.54mm_Vertical
J3: Conn_01x03; PinHeader_1x03_P2.54mm_Vertical; Part Description 3pin 0.1" connector; not fitted
J7: Micro_SD_Card_Det; SDCARD_MOLEX_503398-1892; Part Description 9 (8 + 1) Position Card Connector micro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
J8: THD-20-R; PinHeader_2x20_P2.54mm_Vertical; Part Description PinHeader_2x20_P2.54mm_Vertical
J9: THD-02-R; PinHeader_2x02_P2.54mm_Vertical; Part Description PinHeader_2x02_P2.54mm_Vertical
J14: JST_SHBM04B-SRSS-TB; JST_SH_BM04B-SRSS-TB_1x04-1MP_P1.00mm_Vertical; Part Description 4 pin vertical 1mm pitch connector
Module1: ComputeModule5-CM5; Raspberry-Pi-5-Compute-Module; Part Description 100 Position Connector Receptacle, Cent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
R1, R10: 1k; R_0402_1005Metric; Part Description Resistor 1K M1005 1% 63mW
R2, R3: 470R; R_0402_1005Metric; Part Description Resistor 470R M1005 1% 63mW
R4: nf; R_0805_2012Metric_Pad1.20x1.40mm_HandSolder; not fitted
R5: 0R; R_0805_2012Metric_Pad1.20x1.40mm_HandSolder; Part Description Resistor 0R M2012 5%
SW1: Right angle Tact button; SW_Tactile_SPST_Angled_PTS645Vx58-2LFS; Part Description Right angle through hole Tact switch
TP3, TP5: TestPoint; TestPoint_Pad_2.0x2.0mm; Part Description Test point; not fitted
U1, U2: TPD4EUSB30; USON-10_2.5x1.0mm_P0.5mm; Part Description Quad TVS diode for high speed signals (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
U3: MagJack-A70-112-331N126; TRJG0926HENL; Part Description Gigabit Ethernet Magjack
U5: 74LVC1G07SE-7; SOT-353_SC-70-5; Part Description Buffer, Non-Inverting 1 Element 1 Bit p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
U18: RT9742GGJ5; SOT-23-5; Part Description Power Switch/Driver 1:1 N-Channel 1A TS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

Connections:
/+3.3v: D1.2 (A), D2.2 (A), J8.1, J8.17, Module1.84 (+3.3v_(Output)), Module1.86 (+3.3v_(Output)), R5.1, U3.15 (LEDY_A), U3.17 (LEDG_A), U5.5 (VCC), U18.5 (IN); also elsewhere on the board
/+5v: J8.2, J8.4, J14.1, Module1.77 (+5v_(Input)), Module1.79 (+5v_(Input)), Module1.81 (+5v_(Input)), Module1.83 (+5v_(Input)), Module1.85 (+5v_(Input)), Module1.87 (+5v_(Input)); also elsewhere on the board
/CC1: Module1.94 (CC1); also elsewhere on the board
/CC2: Module1.96 (CC2); also elsewhere on the board
/CM5_GPIO ( Ethernet, GPIO, SDCARD)/+1.8v: Module1.88 (+1.8v_(Output)), Module1.90 (+1.8v_(Output)), R4.1
/CM5_GPIO ( Ethernet, GPIO, SDCARD)/BT_nDis: J3.3, Module1.91 (BT_nDisable)
/CM5_GPIO ( Ethernet, GPIO, SDCARD)/CAM_GPIO0: Module1.97 (CAM_GPIO0); also elsewhere on the board
/CM5_GPIO ( Ethernet, GPIO, SDCARD)/CAM_GPIO1: Module1.100 (CAM_GPIO1); also elsewhere on the board
/CM5_GPIO ( Ethernet, GPIO, SDCARD)/EEPROM_nWP: J2.4, Module1.20 (EEPROM_nWP)
/CM5_GPIO ( Ethernet, GPIO, SDCARD)/ETH_LEDG: Module1.17 (Ethernet_nLED2(3.3v)), R2.2
/CM5_GPIO ( Ethernet, GPIO, SDCARD)/ETH_LEDY: Module1.15 (Ethernet_nLED3(3.3v)), R3.2
/CM5_GPIO ( Ethernet, GPIO, SDCARD)/GPIO2: J8.3, Module1.58 (GPIO2)
/CM5_GPIO ( Ethernet, GPIO, SDCARD)/GPIO3: J8.5, Module1.56 (GPIO3)
/CM5_GPIO ( Ethernet, GPIO, SDCARD)/GPIO4: J8.7, Module1.54 (GPIO4)
/CM5_GPIO ( Ethernet, GPIO, SDCARD)/GPIO5: J8.29, Module1.34 (GPIO5)
/CM5_GPIO ( Ethernet, GPIO, SDCARD)/GPIO6: J8.31, Module1.30 (GPIO6)
/CM5_GPIO ( Ethernet, GPIO, SDCARD)/GPIO7: J8.26, Module1.37 (GPIO7)
/CM5_GPIO ( Ethernet, GPIO, SDCARD)/GPIO8: J8.24, Module1.39 (GPIO8)
/CM5_GPIO ( Ethernet, GPIO, SDCARD)/GPIO9: J8.21, Module1.40 (GPIO9)
/CM5_GPIO ( Ethernet, GPIO, SDCARD)/GPIO10: J8.19, Module1.44 (GPIO10)
/CM5_GPIO ( Ethernet, GPIO, SDCARD)/GPIO11: J8.23, Module1.38 (GPIO11)
/CM5_GPIO ( Ethernet, GPIO, SDCARD)/GPIO12: J8.32, Module1.31 (GPIO12)
/CM5_GPIO ( Ethernet, GPIO, SDCARD)/GPIO13: J8.33, Module1.28 (GPIO13)
/CM5_GPIO ( Ethernet, GPIO, SDCARD)/GPIO14: J8.8, Module1.55 (GPIO14)
/CM5_GPIO ( Ethernet, GPIO, SDCARD)/GPIO15: J8.10, Module1.51 (GPIO15)
/CM5_GPIO ( Ethernet, GPIO, SDCARD)/GPIO16: J8.36, Module1.29 (GPIO16)
/CM5_GPIO ( Ethernet, GPIO, SDCARD)/GPIO17: J8.11, Module1.50 (GPIO17)
/CM5_GPIO ( Ethernet, GPIO, SDCARD)/GPIO18: J8.12, Module1.49 (GPIO18)
/CM5_GPIO ( Ethernet, GPIO, SDCARD)/GPIO19: J8.35, Module1.26 (GPIO19)
/CM5_GPIO ( Ethernet, GPIO, SDCARD)/GPIO20: J8.38, Module1.27 (GPIO20)
/CM5_GPIO ( Ethernet, GPIO, SDCARD)/GPIO21: J8.40, Module1.25 (GPIO21)
/CM5_GPIO ( Ethernet, GPIO, SDCARD)/GPIO22: J8.15, Module1.46 (GPIO22)
/CM5_GPIO ( Ethernet, GPIO, SDCARD)/GPIO23: J8.16, Module1.47 (GPIO23)
/CM5_GPIO ( Ethernet, GPIO, SDCARD)/GPIO24: J8.18, Module1.45 (GPIO24)
/CM5_GPIO ( Ethernet, GPIO, SDCARD)/GPIO25: J8.22, Module1.41 (GPIO25)
/CM5_GPIO ( Ethernet, GPIO, SDCARD)/GPIO26: J8.37, Module1.24 (GPIO26)
/CM5_GPIO ( Ethernet, GPIO, SDCARD)/GPIO27: J8.13, Module1.48 (GPIO27)
/CM5_GPIO ( Ethernet, GPIO, SDCARD)/GPIO_VREF: Module1.78 (GPIO_VREF(1.8v/3.3v_Input)), R4.2, R5.2; also elsewhere on the board
/CM5_GPIO ( Ethernet, GPIO, SDCARD)/ID_SC: J8.28, Module1.35 (ID_SC); also elsewhere on the board
/CM5_GPIO ( Ethernet, GPIO, SDCARD)/ID_SD: J8.27, Module1.36 (ID_SD); also elsewhere on the board
/CM5_GPIO ( Ethernet, GPIO, SDCARD)/PMIC_ENABLE: J2.12, Module1.99 (PMIC_ENABLE)
/CM5_GPIO ( Ethernet, GPIO, SDCARD)/PWM: J14.2, Module1.19 (FAN_PWM)
/CM5_GPIO ( Ethernet, GPIO, SDCARD)/PWR_BUT: J2.14, Module1.92 (PWR_BUT), SW1.1
/CM5_GPIO ( Ethernet, GPIO, SDCARD)/SD_CLK: J7.5 (CLK), Module1.57 (SD_CLK)
/CM5_GPIO ( Ethernet, GPIO, SDCARD)/SD_CMD: J7.3 (CMD), Module1.62 (SD_CMD)
/CM5_GPIO ( Ethernet, GPIO, SDCARD)/SD_DAT0: J7.7 (DAT0), Module1.63 (SD_DAT0)
/CM5_GPIO ( Ethernet, GPIO, SDCARD)/SD_DAT1: J7.8 (DAT1), Module1.67 (SD_DAT1)
/CM5_GPIO ( Ethernet, GPIO, SDCARD)/SD_DAT2: J7.1 (DAT2), Module1.69 (SD_DAT2)
/CM5_GPIO ( Ethernet, GPIO, SDCARD)/SD_DAT3: J7.2 (DAT3/CD), Module1.61 (SD_DAT3)
/CM5_GPIO ( Ethernet, GPIO, SDCARD)/SD_PWR: C5.1, J7.4 (VDD), U18.1 (OUT)
/CM5_GPIO ( Ethernet, GPIO, SDCARD)/SD_PWR_ON: Module1.75 (SD_PWR_ON), U18.4 (EN)
/CM5_GPIO ( Ethernet, GPIO, SDCARD)/SYNC_OUT: J2.6, Module1.18 (Ethernet_SYNC_OUT(1.8v))
/CM5_GPIO ( Ethernet, GPIO, SDCARD)/TACHO: J14.4, Module1.16 (FAN_TACHO)
/CM5_GPIO ( Ethernet, GPIO, SDCARD)/TR0_TAP: J9.3, U3.11 (VC1)
/CM5_GPIO ( Ethernet, GPIO, SDCARD)/TR1_TAP: J9.1, U3.12 (VC2)
/CM5_GPIO ( Ethernet, GPIO, SDCARD)/TR2_TAP: J9.2, U3.13 (VC3)
/CM5_GPIO ( Ethernet, GPIO, SDCARD)/TR3_TAP: J9.4, U3.14 (VC4)
/CM5_GPIO ( Ethernet, GPIO, SDCARD)/TRD0_N: Module1.10 (Ethernet_Pair0_N), U2.4 (D2+), U2.7, U3.2 (TRD0-)
/CM5_GPIO ( Ethernet, GPIO, SDCARD)/TRD0_P: Module1.12 (Ethernet_Pair0_P), U2.5 (D2-), U2.6, U3.1 (TRD0+)
/CM5_GPIO ( Ethernet, GPIO, SDCARD)/TRD1_N: Module1.6 (Ethernet_Pair1_N), U2.2 (D1-), U2.9, U3.6 (TRD1-)
/CM5_GPIO ( Ethernet, GPIO, SDCARD)/TRD1_P: Module1.4 (Ethernet_Pair1_P), U2.1 (D1+), U2.10, U3.3 (TRD1+)
/CM5_GPIO ( Ethernet, GPIO, SDCARD)/TRD2_N: Module1.9 (Ethernet_Pair2_N), U1.4 (D2+), U1.7, U3.8 (TRD2-)
/CM5_GPIO ( Ethernet, GPIO, SDCARD)/TRD2_P: Module1.11 (Ethernet_Pair2_P), U1.5 (D2-), U1.6, U3.7 (TRD2+)
/CM5_GPIO ( Ethernet, GPIO, SDCARD)/TRD3_N: Module1.5 (Ethernet_Pair3_N), U1.2 (D1-), U1.9, U3.10 (TRD3-)
/CM5_GPIO ( Ethernet, GPIO, SDCARD)/TRD3_P: Module1.3 (Ethernet_Pair3_P), U1.1 (D1+), U1.10, U3.9 (TRD3+)
/CM5_GPIO ( Ethernet, GPIO, SDCARD)/USBOTG: J2.10; also elsewhere on the board
/CM5_GPIO ( Ethernet, GPIO, SDCARD)/VBAT: BT1.1 (+), Module1.76 (VBAT)
/CM5_GPIO ( Ethernet, GPIO, SDCARD)/WL_nDis: J3.1, Module1.89 (WiFi_nDisable)
/CM5_GPIO ( Ethernet, GPIO, SDCARD)/nPWR_LED: Module1.95 (LED_nPWR), U5.2
/CM5_GPIO ( Ethernet, GPIO, SDCARD)/nRPIBOOT: J2.2, Module1.93 (nRPIBOOT)
/CM5_HighSpeed/SCL0: Module1.80 (SCL0); also elsewhere on the board
/CM5_HighSpeed/SDA0: Module1.82 (SDA0); also elsewhere on the board
GND: BT1.2 (-), C1.2, C5.2, J2.1, J2.3, J2.5, J2.7, J2.9, J2.11, J2.13, J3.2, J7.6 (VSS), J7.11 (SHIELD), J8.6, J8.9, J8.14, J8.20, J8.25, J8.30, J8.34, J8.39, J14.3, Module1.1 (GND), Module1.2 (GND), Module1.7 (GND), Module1.8 (GND), Module1.13 (GND), Module1.14 (GND), Module1.22 (GND), Module1.23 (GND), Module1.32 (GND), Module1.33 (GND), Module1.42 (GND), Module1.43 (GND), Module1.52 (GND), Module1.53 (GND), Module1.59 (GND), Module1.60 (GND), Module1.65 (GND), Module1.66 (GND), Module1.71 (GND), Module1.74 (GND), Module1.98 (GND), SW1.2, U1.3 (GND), U1.8 (GND), U2.3 (GND), U2.8 (GND), U3.19 (SHIELD), U3.20 (SHIELD), U5.3 (GND), U18.2 (GND); also elsewhere on the board
unnamed: C1.1, U3.4 (CT), U3.5 (CT)
unnamed: D1.1 (K), R10.1, TP5.1
unnamed: D2.1 (K), R1.1, TP3.1
unnamed: Module1.21 (LED_nACT), R1.2
unnamed: R10.2, U5.4
unnamed: R3.1, U3.18 (LEDG_K)
unnamed: R2.1, U3.16 (LEDY_K)

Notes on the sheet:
40Way GPIO Header
Activity LED
FAN connector
Ethernet POE Protection
GPIO Voltage select
Not Fitted header
POE Header
Force RPIBOOT = Jumper Pins 1-2
PWR LED
Ethernet
CM5Lite SDCARD I/F

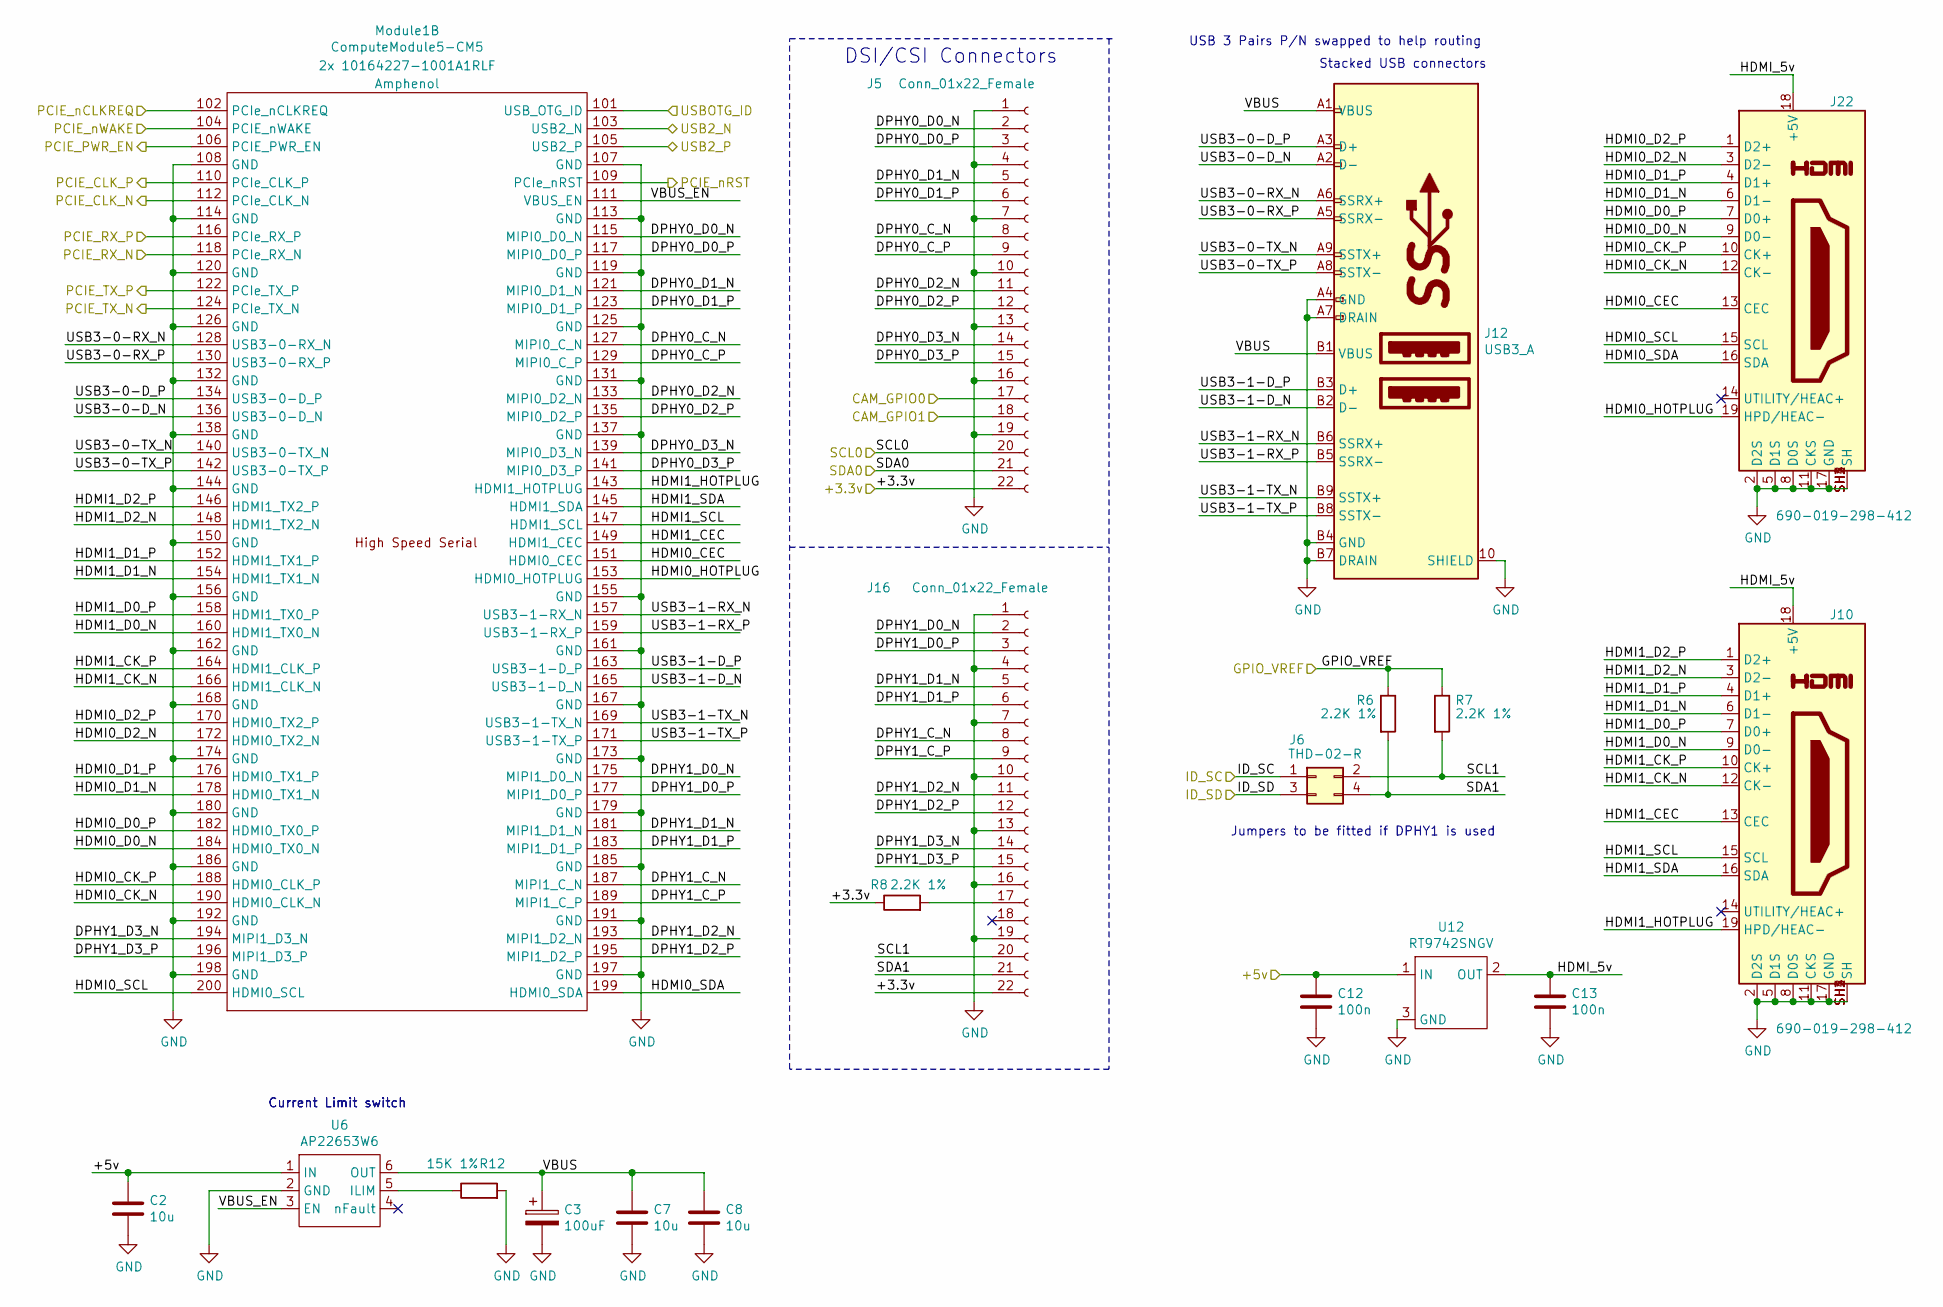
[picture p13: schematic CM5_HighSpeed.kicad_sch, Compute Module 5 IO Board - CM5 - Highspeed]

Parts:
C2, C7, C8: 10u; C_0805_2012Metric; Part Description 10uF 10% 10V Ceramic Capacitor X7R 0805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
C3: 100uF; CP_EIA-7343-31_Kemet-D; Part Description Capacitor, SP-Cap, 100u, 6.3V, 15mR ESR
C12, C13: 100n; C_0402_1005Metric; Part Description 0.1uF 10% 16V Ceramic Capacitor X7R 040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
J5, J16: Conn_01x22_Female; Hirose_FH12-22S-0.5SH_1x22-1MP_P0.50mm_Horizontal; Part Description 22 Position FFC, FPC Connector Contacts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
J6: THD-02-R; PinHeader_2x02_P2.54mm_Vertical; Part Description PinHeader_2x02_P2.54mm_Vertical
J10, J22: 690-019-298-412; EDAC 690-019-298-412; Part Description HDMI Connector, Right Angle, 19 Contact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
J12: USB3_A; MTCONN_UBAF30-D2011; Part Description Dual USB 3 connector
Module1: ComputeModule5-CM5; Raspberry-Pi-5-Compute-Module; Part Description 100 Position Connector Receptacle, Cent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
R6, R7, R8: 2.2K 1%; R_0402_1005Metric; Part Description Resistor 2.2K M1005 1% 63mW
R12: 15K 1%; R_0402_1005Metric; Part Description Resistor 15K M1005 1% 63mW
U6: AP22653W6; SOT-23-6; Part Description Power Switch/Driver 1:1 P-Channel 2.1A 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
U12: RT9742SNGV; TSOT-23_HandSoldering; Part Description Power Switch/Driver 1:1 N-Channel 500mA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

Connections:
/+3.3v: J5.22, J16.22, R8.1; also elsewhere on the board
/+5v: C2.1, C12.1, U6.1 (IN), U12.1 (IN); also elsewhere on the board
/CM5_GPIO ( Ethernet, GPIO, SDCARD)/CAM_GPIO0: J5.17; also elsewhere on the board
/CM5_GPIO ( Ethernet, GPIO, SDCARD)/CAM_GPIO1: J5.18; also elsewhere on the board
/CM5_GPIO ( Ethernet, GPIO, SDCARD)/GPIO_VREF: R6.1, R7.1; also elsewhere on the board
/CM5_GPIO ( Ethernet, GPIO, SDCARD)/ID_SC: J6.1; also elsewhere on the board
/CM5_GPIO ( Ethernet, GPIO, SDCARD)/ID_SD: J6.3; also elsewhere on the board
/CM5_GPIO ( Ethernet, GPIO, SDCARD)/USBOTG: Module1.101 (USB_OTG_ID); also elsewhere on the board
/CM5_HighSpeed/DPHY0_C_N: J5.8, Module1.127 (DPHY0_C_N)
/CM5_HighSpeed/DPHY0_C_P: J5.9, Module1.129 (DPHY0_C_P)
/CM5_HighSpeed/DPHY0_D0_N: J5.2, Module1.115 (DPHY0_D0_N)
/CM5_HighSpeed/DPHY0_D0_P: J5.3, Module1.117 (DPHY0_D0_P)
/CM5_HighSpeed/DPHY0_D1_N: J5.5, Module1.121 (DPHY0_D1_N)
/CM5_HighSpeed/DPHY0_D1_P: J5.6, Module1.123 (DPHY0_D1_P)
/CM5_HighSpeed/DPHY0_D2_N: J5.11, Module1.133 (DPHY0_D2_N)
/CM5_HighSpeed/DPHY0_D2_P: J5.12, Module1.135 (DPHY0_D2_P)
/CM5_HighSpeed/DPHY0_D3_N: J5.14, Module1.139 (DPHY0_D3_N)
/CM5_HighSpeed/DPHY0_D3_P: J5.15, Module1.141 (DPHY0_D3_P)
/CM5_HighSpeed/DPHY1_C_N: J16.8, Module1.187 (DPHY1_C_N)
/CM5_HighSpeed/DPHY1_C_P: J16.9, Module1.189 (DPHY1_C_P)
/CM5_HighSpeed/DPHY1_D0_N: J16.2, Module1.175 (DPHY1_D0_N)
/CM5_HighSpeed/DPHY1_D0_P: J16.3, Module1.177 (DPHY1_D0_P)
/CM5_HighSpeed/DPHY1_D1_N: J16.5, Module1.181 (DPHY1_D1_N)
/CM5_HighSpeed/DPHY1_D1_P: J16.6, Module1.183 (DPHY1_D1_P)
/CM5_HighSpeed/DPHY1_D2_N: J16.11, Module1.193 (DPHY1_D2_N)
/CM5_HighSpeed/DPHY1_D2_P: J16.12, Module1.195 (DPHY1_D2_P)
/CM5_HighSpeed/DPHY1_D3_N: J16.14, Module1.194 (DPHY1_D3_N)
/CM5_HighSpeed/DPHY1_D3_P: J16.15, Module1.196 (DPHY1_D3_P)
/CM5_HighSpeed/HDMI0_CEC: J22.13 (CEC), Module1.151 (HDMI0_CEC)
/CM5_HighSpeed/HDMI0_CK_N: J22.12 (CK-), Module1.190 (HDMI0_CLK_N)
/CM5_HighSpeed/HDMI0_CK_P: J22.10 (CK+), Module1.188 (HDMI0_CLK_P)
/CM5_HighSpeed/HDMI0_D0_N: J22.9 (D0-), Module1.184 (HDMI0_TX0_N)
/CM5_HighSpeed/HDMI0_D0_P: J22.7 (D0+), Module1.182 (HDMI0_TX0_P)
/CM5_HighSpeed/HDMI0_D1_N: J22.6 (D1-), Module1.178 (HDMI0_TX1_N)
/CM5_HighSpeed/HDMI0_D1_P: J22.4 (D1+), Module1.176 (HDMI0_TX1_P)
/CM5_HighSpeed/HDMI0_D2_N: J22.3 (D2-), Module1.172 (HDMI0_TX2_N)
/CM5_HighSpeed/HDMI0_D2_P: J22.1 (D2+), Module1.170 (HDMI0_TX2_P)
/CM5_HighSpeed/HDMI0_HOTPLUG: J22.19 (HPD/HEAC-), Module1.153 (HDMI0_HOTPLUG)
/CM5_HighSpeed/HDMI0_SCL: J22.15 (SCL), Module1.200 (HDMI0_SCL)
/CM5_HighSpeed/HDMI0_SDA: J22.16 (SDA), Module1.199 (HDMI0_SDA)
/CM5_HighSpeed/HDMI1_CEC: J10.13 (CEC), Module1.149 (HDMI1_CEC)
/CM5_HighSpeed/HDMI1_CK_N: J10.12 (CK-), Module1.166 (HDMI1_CLK_N)
/CM5_HighSpeed/HDMI1_CK_P: J10.10 (CK+), Module1.164 (HDMI1_CLK_P)
/CM5_HighSpeed/HDMI1_D0_N: J10.9 (D0-), Module1.160 (HDMI1_TX0_N)
/CM5_HighSpeed/HDMI1_D0_P: J10.7 (D0+), Module1.158 (HDMI1_TX0_P)
/CM5_HighSpeed/HDMI1_D1_N: J10.6 (D1-), Module1.154 (HDMI1_TX1_N)
/CM5_HighSpeed/HDMI1_D1_P: J10.4 (D1+), Module1.152 (HDMI1_TX1_P)
/CM5_HighSpeed/HDMI1_D2_N: J10.3 (D2-), Module1.148 (HDMI1_TX2_N)
/CM5_HighSpeed/HDMI1_D2_P: J10.1 (D2+), Module1.146 (HDMI1_TX2_P)
/CM5_HighSpeed/HDMI1_HOTPLUG: J10.19 (HPD/HEAC-), Module1.143 (HDMI1_HOTPLUG)
/CM5_HighSpeed/HDMI1_SCL: J10.15 (SCL), Module1.147 (HDMI1_SCL)
/CM5_HighSpeed/HDMI1_SDA: J10.16 (SDA), Module1.145 (HDMI1_SDA)
/CM5_HighSpeed/HDMI_5v: C13.1, J10.18 (+5V), J22.18 (+5V), U12.2 (OUT)
/CM5_HighSpeed/PCIE_CLK_N: Module1.112 (PCIe_CLK_N); also elsewhere on the board
/CM5_HighSpeed/PCIE_CLK_P: Module1.110 (PCIe_CLK_P); also elsewhere on the board
/CM5_HighSpeed/PCIE_PWR_EN: Module1.106 (PCIE_PWR_EN); also elsewhere on the board
/CM5_HighSpeed/PCIE_RX_N: Module1.118 (PCIe_RX_N); also elsewhere on the board
/CM5_HighSpeed/PCIE_RX_P: Module1.116 (PCIe_RX_P); also elsewhere on the board
/CM5_HighSpeed/PCIE_TX_N: Module1.124 (PCIe_TX_N); also elsewhere on the board
/CM5_HighSpeed/PCIE_TX_P: Module1.122 (PCIe_TX_P); also elsewhere on the board
/CM5_HighSpeed/PCIE_nCLKREQ: Module1.102 (PCIe_nCLKREQ); also elsewhere on the board
/CM5_HighSpeed/PCIE_nRST: Module1.109 (PCIe_nRST); also elsewhere on the board
/CM5_HighSpeed/PCIE_nWAKE: Module1.104 (PCIE_nWAKE); also elsewhere on the board
/CM5_HighSpeed/SCL0: J5.20; also elsewhere on the board
/CM5_HighSpeed/SCL1: J6.2, J16.20, R7.2
/CM5_HighSpeed/SDA0: J5.21; also elsewhere on the board
/CM5_HighSpeed/SDA1: J6.4, J16.21, R6.2
/CM5_HighSpeed/USB3-0-D_N: J12.A2 (D-), Module1.136 (USB3-0-D_N)
/CM5_HighSpeed/USB3-0-D_P: J12.A3 (D+), Module1.134 (USB3-0-D_P)
/CM5_HighSpeed/USB3-0-RX_N: J12.A6 (SSRX+), Module1.128 (USB3-0-RX_N)
/CM5_HighSpeed/USB3-0-RX_P: J12.A5 (SSRX-), Module1.130 (USB3-0-RX_P)
/CM5_HighSpeed/USB3-0-TX_N: J12.A9 (SSTX+), Module1.140 (USB3-0-TX_N)
/CM5_HighSpeed/USB3-0-TX_P: J12.A8 (SSTX-), Module1.142 (USB3-0-TX_P)
/CM5_HighSpeed/USB3-1-D_N: J12.B2 (D-), Module1.165 (USB3-1-D_N)
/CM5_HighSpeed/USB3-1-D_P: J12.B3 (D+), Module1.163 (USB3-1-D_P)
/CM5_HighSpeed/USB3-1-RX_N: J12.B6 (SSRX+), Module1.157 (USB3-1-RX_N)
/CM5_HighSpeed/USB3-1-RX_P: J12.B5 (SSRX-), Module1.159 (USB3-1-RX_P)
/CM5_HighSpeed/USB3-1-TX_N: J12.B9 (SSTX+), Module1.169 (USB3-1-TX_N)
/CM5_HighSpeed/USB3-1-TX_P: J12.B8 (SSTX-), Module1.171 (USB3-1-TX_P)
/CM5_HighSpeed/VBUS: C3.1, C7.1, C8.1, J12.A1 (VBUS), J12.B1 (VBUS), U6.6 (OUT)
/CM5_HighSpeed/VBUS_EN: Module1.111 (VBUS_EN), U6.3 (EN)
/USB2_N: Module1.103 (USB2_N); also elsewhere on the board
/USB2_P: Module1.105 (USB2_P); also elsewhere on the board
GND: C2.2, C3.2, C7.2, C8.2, C12.2, C13.2, J5.1, J5.4, J5.7, J5.10, J5.13, J5.16, J5.19, J10.2 (D2S), J10.5 (D1S), J10.8 (D0S), J10.11 (CKS), J10.17 (GND), J10.SH1 (SH), J10.SH2 (SH), J10.SH3 (SH), J10.SH4 (SH), J12.10 (SHIELD), J12.A4 (GND), J12.A7 (DRAIN), J12.B4 (GND), J12.B7 (DRAIN), J16.1, J16.4, J16.7, J16.10, J16.13, J16.16, J16.19, J22.2 (D2S), J22.5 (D1S), J22.8 (D0S), J22.11 (CKS), J22.17 (GND), J22.SH1 (SH), J22.SH2 (SH), J22.SH3 (SH), J22.SH4 (SH), Module1.107 (GND), Module1.108 (GND), Module1.113 (GND), Module1.114 (GND), Module1.119 (GND), Module1.120 (GND), Module1.125 (GND), Module1.126 (GND), Module1.131 (GND), Module1.132 (GND), Module1.137 (GND), Module1.138 (GND), Module1.144 (GND), Module1.150 (GND), Module1.155 (GND), Module1.156 (GND), Module1.161 (GND), Module1.162 (GND), Module1.167 (GND), Module1.168 (GND), Module1.173 (GND), Module1.174 (GND), Module1.179 (GND), Module1.180 (GND), Module1.185 (GND), Module1.186 (GND), Module1.191 (GND), Module1.192 (GND), Module1.197 (GND), Module1.198 (GND), R12.2, U6.2 (GND), U12.3 (GND); also elsewhere on the board
unnamed: J16.17, R8.2
unnamed: R12.1, U6.5 (ILIM)

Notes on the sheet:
USB 3 Pairs P/N swapped to help routing
Jumpers to be fitted if DPHY1 is used
Current Limit switch
DSI/CSI Connectors
Stacked USB connectors

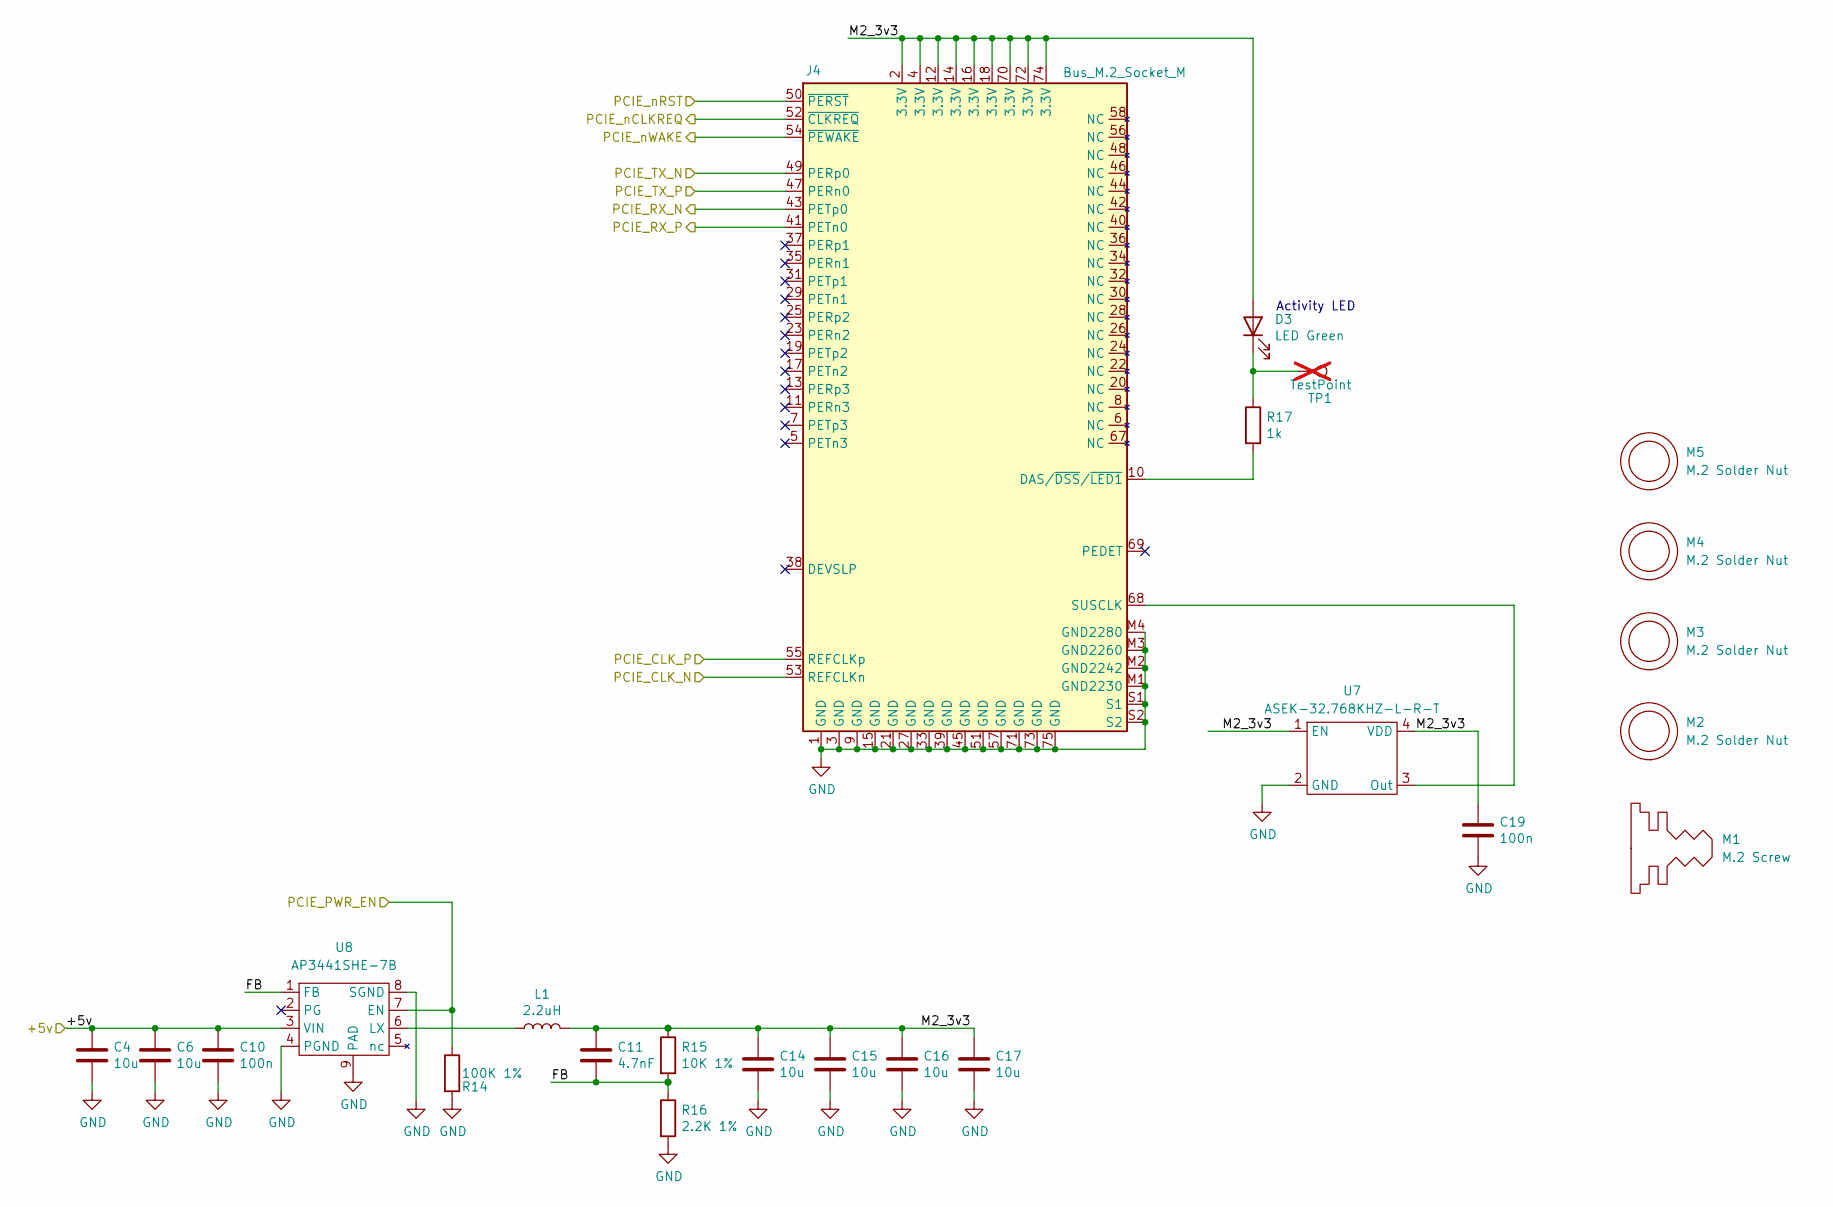
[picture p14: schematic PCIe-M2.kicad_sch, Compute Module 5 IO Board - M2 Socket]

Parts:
C4, C6, C14, C15, C16, C17: 10u; C_0805_2012Metric; Part Description 10uF 10% 10V Ceramic Capacitor X7R 0805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
C10, C19: 100n; C_0402_1005Metric; Part Description 0.1uF 10% 16V Ceramic Capacitor X7R 040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
C11: 4.7nF; C_0402_1005Metric; Part Description 4.7nF capacitor 0402
D3: LED Green; LED_0603_1608Metric; Part Description Green 572nm LED Indication - Discrete 2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
J4: Bus_M.2_Socket_M; M.2 M Key socket; Part Description M.2 M Key connector
L1: 2.2uH; L_Bourns_SRP5030CC; Part Description Inductor, SMT, 2520, 2u2, IRMS=7A, ISAT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
M1: M.2 Screw; Part Description M.2 Screw
M2, M3, M4, M5: M.2 Solder Nut; Part Description Solder nut for M.2 slot
R14: 100K 1%; R_0402_1005Metric; Part Description Resistor 100K M1005 1% 63mW
R15: 10K 1%; R_0402_1005Metric; Part Description Resistor 10K M1005 1% 63mW
R16: 2.2K 1%; R_0402_1005Metric; Part Description Resistor 2.2K M1005 1% 63mW
R17: 1k; R_0402_1005Metric; Part Description Resistor 1K M1005 1% 63mW
TP1: TestPoint; TestPoint_Pad_2.0x2.0mm; Part Description Test point; not fitted
U7: ASEK-32.768KHZ-L-R-T; Crystal_SMD_3225-4Pin_3.2x2.5mm; Part Description 32KHz Xtal oscilator
U8: AP3441SHE-7B; DFN-8-1EP_2x2mm_P0.5mm_EP1.05x1.75mm; Part Description 3A DC-DC converter

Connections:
/+5v: C4.1, C6.1, C10.1, U8.3 (VIN); also elsewhere on the board
/CM5_HighSpeed/PCIE_CLK_N: J4.53 (REFCLKn); also elsewhere on the board
/CM5_HighSpeed/PCIE_CLK_P: J4.55 (REFCLKp); also elsewhere on the board
/CM5_HighSpeed/PCIE_PWR_EN: R14.1, U8.7 (EN); also elsewhere on the board
/CM5_HighSpeed/PCIE_RX_N: J4.43 (PETp0); also elsewhere on the board
/CM5_HighSpeed/PCIE_RX_P: J4.41 (PETn0); also elsewhere on the board
/CM5_HighSpeed/PCIE_TX_N: J4.49 (PERp0); also elsewhere on the board
/CM5_HighSpeed/PCIE_TX_P: J4.47 (PERn0); also elsewhere on the board
/CM5_HighSpeed/PCIE_nCLKREQ: J4.52 (~CLKREQ); also elsewhere on the board
/CM5_HighSpeed/PCIE_nRST: J4.50 (~PERST); also elsewhere on the board
/CM5_HighSpeed/PCIE_nWAKE: J4.54 (~PEWAKE); also elsewhere on the board
/PCIe-M2/FB: C11.2, R15.2, R16.1, U8.1 (FB)
/PCIe-M2/M2_3v3: C11.1, C14.1, C15.1, C16.1, C17.1, C19.1, D3.2 (A), J4.2 (3.3V), J4.4 (3.3V), J4.12 (3.3V), J4.14 (3.3V), J4.16 (3.3V), J4.18 (3.3V), J4.70 (3.3V), J4.72 (3.3V), J4.74 (3.3V), L1.2, R15.1, U7.1 (EN), U7.4 (VDD)
GND: C4.2, C6.2, C10.2, C14.2, C15.2, C16.2, C17.2, C19.2, J4.1 (GND), J4.3 (GND), J4.9 (GND), J4.15 (GND), J4.21 (GND), J4.27 (GND), J4.33 (GND), J4.39 (GND), J4.45 (GND), J4.51 (GND), J4.57 (GND), J4.71 (GND), J4.73 (GND), J4.75 (GND), J4.M1 (GND2230), J4.M2 (GND2242), J4.M3 (GND2260), J4.M4 (GND2280), J4.S1, J4.S2, R14.2, R16.2, U7.2 (GND), U8.4 (PGND), U8.8 (SGND), U8.9 (PAD); also elsewhere on the board
unnamed: D3.1 (K), R17.1, TP1.1
unnamed: J4.10 (DAS/~DSS/~LED1), R17.2
unnamed: J4.68 (SUSCLK), U7.3 (Out)
unnamed: L1.1, U8.6 (LX)

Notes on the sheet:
Activity LED

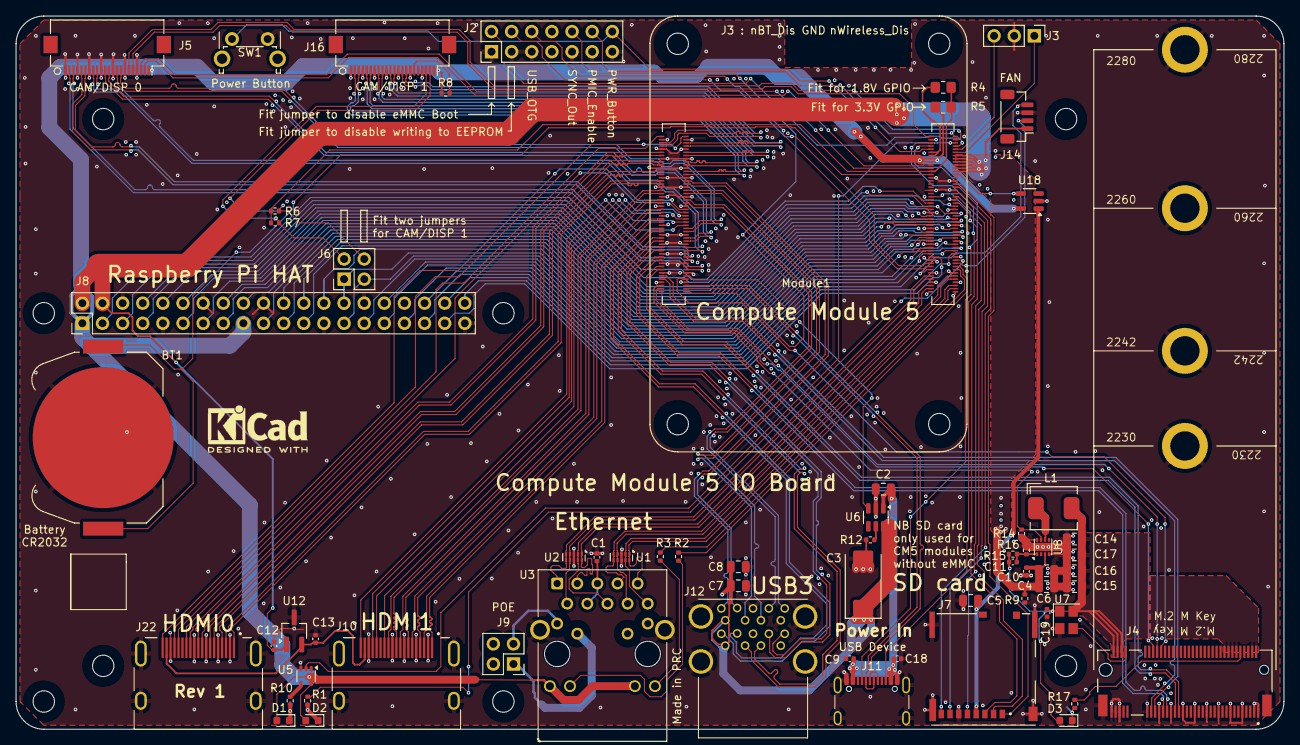
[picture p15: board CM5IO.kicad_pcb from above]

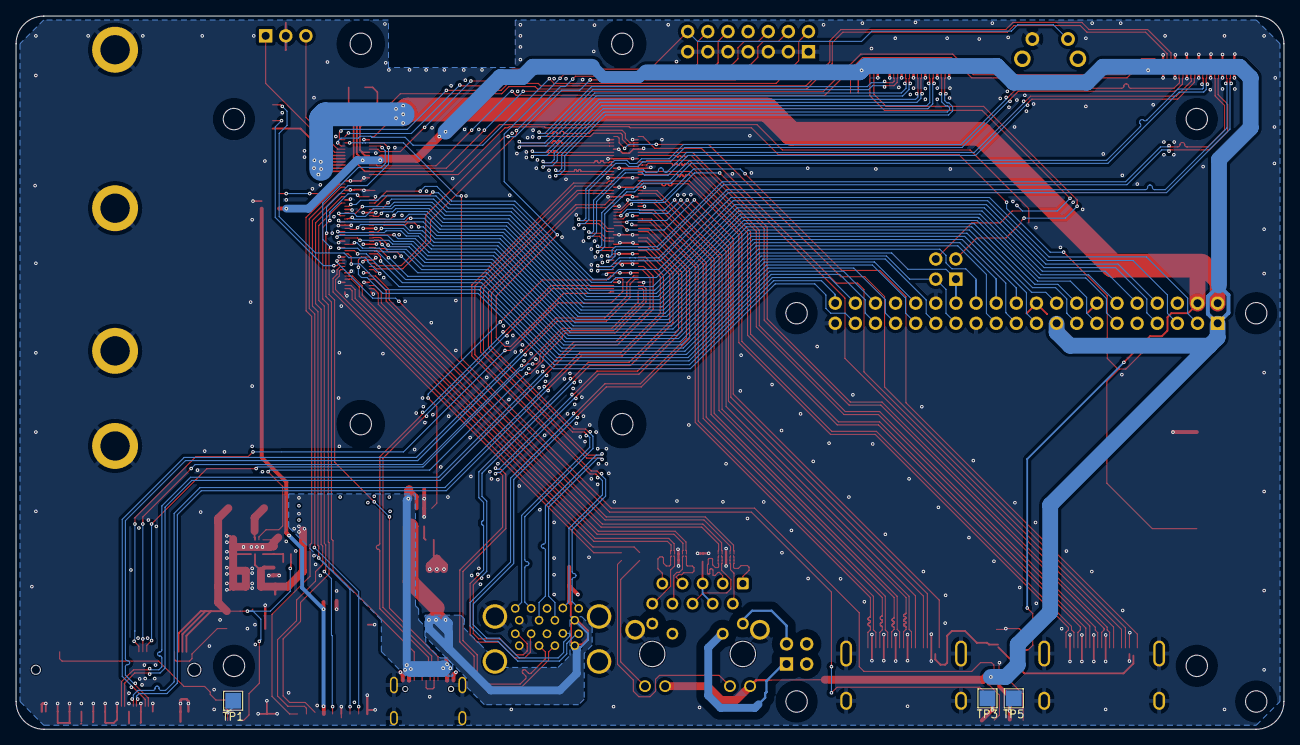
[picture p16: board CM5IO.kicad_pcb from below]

Board: 4 copper layers, 160.0 x 90.0 mm, 76 parts (3 on the bottom side), 161 nets.

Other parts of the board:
logo1: KiCad-Logo2_5mm_SilkScreen

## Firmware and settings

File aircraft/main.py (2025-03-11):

import threading
import time
import serial
import os
from pymavlink import mavutil
import sys
import socket
import json
from com import communication
import subprocess
import signal

def stream_video(stop_event):
    """
    Stream UDP
    """

    cmd = (
        "gst-launch-1.0 libcamerasrc ! "
        "'video/x-raw,width=640,height=480,format=NV12,framerate=30/1' ! "
        "videoconvert ! "
        "jpegenc quality=50 ! "
        "rtpjpegpay ! "
        "udpsink host=192.168.2.1 port=7777"
    )

    process = subprocess.Popen(
        cmd,
        shell=True,
        preexec_fn=os.setsid
    )

    try:
        while process.poll() is None:
            if stop_event.is_set():
                print("[INFO] Stopping gstreamer")
                os.killpg(os.getpgid(process.pid), signal.SIGTERM)
                break
            time.sleep(0.1)

    finally:
        process.wait()
        print("[INFO] Gstreamer pipeline terminated.")

def update_channel(stop_event):
    self_ip = "192.168.2.2"
    crsf_port = 4444

    com = communication(com_port='/dev/ttyUSB0')

    # Start the communication transmit thread
    thread = threading.Thread(target=com.transmit, daemon=True)
    thread.start()

    # Define PWM channel configurations
    disarm_channels = [
        1500, 1500, 885, 1500, 1000, 1500, 1500, 1500,
        1500, 1500, 1500, 1500, 1500, 1500, 1500, 1500
    ]

    arm_channels = [
        1500, 1500, 885, 1500, 1800, 1500, 1500, 1500,
        1500, 1500, 1500, 1500, 1500, 1500, 1500, 1500
    ]

    axis_to_channel = {
        'roll': 0,
        'pitch': 1,
        'yaw': 2,
        'throttle': 3
    }

    try:
        # Initialize the drone in a disarmed state
        com.update_data(disarm_channels)
        print("[STATUS] Disarm sequence on startup.")
        armed = False  # Flag to track arming state
        time.sleep(1)  # Brief pause to ensure commands are sent

        with socket.socket(socket.AF_INET, socket.SOCK_DGRAM) as udp_socket:
            udp_socket.bind((self_ip, crsf_port))
            print(f"[STATUS] UDP: Listening on {self_ip}:{crsf_port}")

            while not stop_event.is_set():
                try:
                    udp_socket.settimeout(1.0)  # 1-second timeout for receiving data
                    data, addr = udp_socket.recvfrom(1024)  # Buffer size of 1024 bytes

                    decoded_data = data.decode('utf-8')

                    recv_dict = json.loads(decoded_data)
                    print(f"[DEBUG] Received data from {addr}: {recv_dict}")

                    # Extract axes and buttons data
                    axes = recv_dict.get('axes', {})
                    buttons = recv_dict.get('buttons', {})

                    # Get the state of Button 0 (default to 0 if not present)
                    button_0_state = buttons.get('0', 0)

                    # Handle arming based on Button 0 state
                    if button_0_state == 1 and not armed:
                        # Button 0 pressed: Arm the drone
                        com.update_data(arm_channels)
                        print("[INFO] Arm command sent.")
                        armed = True
                        time.sleep(0.1)  # Short pause to prevent rapid toggling
                    elif button_0_state == 0 and armed:
                        # Button 0 released: Disarm the drone
                        com.update_data(disarm_channels)
                        print("[INFO] Disarm command sent.")
                        armed = False
                        time.sleep(0.1)  # Short pause to prevent rapid toggling

                    if armed:
                        # If armed, update PWM channels based on joystick axes
                        channels_pwm = arm_channels.copy()

                        for axis, channel in axis_to_channel.items():
                            axis_value = axes.get(axis, channels_pwm[channel])

                            if not isinstance(axis_value, int):
                                print(f"[WARNING] Invalid value for {axis}: {axis_value}. Skipping.")
                                continue

                            channels_pwm[channel] = axis_value

                        com.update_data(channels_pwm)
                        print(f"[INFO] Updated PWM channels: {channels_pwm}")
                    else:
                        # If disarmed, ensure PWM channels are set to disarmed state
                        com.update_data(disarm_channels)
                        print("[INFO] Drone is disarmed. PWM channels set to disarm.")

                except socket.timeout:

                    current_time = time.time()
                    time_since_last = current_time - last_received_time

                    if time_since_last > 2.0 and armed:
                        com.update_data(disarm_channels)
                        print("[WARNING] No command packets received for 2 seconds. Disarming drone.")
                        armed = False

                except json.JSONDecodeError:
                    print(f"[ERROR] Received invalid JSON data from {addr}: {data}")
                except Exception as e:
                    print(f"[ERROR] {e}")

    except KeyboardInterrupt:
        print("\n[INFO] Stopping PWM channel updates.")
        com.join()
    except Exception as e:
        print(f"[ERROR] {e}")
    finally:
        # Ensure the drone is disarmed on exit
        com.update_data(disarm_channels)
        print("[INFO] Disarmed channels. Exiting PWM channel thread.")


def mavlink_telem(stop_event):
    """
    UART mavlink data handler
    """

    target_ip = "192.168.2.1"
    tcp_port = 9999

    serial_port = '/dev/ttyUSB1'
    baud_rate = 115200

    try:
        master = mavutil.mavlink_connection(serial_port, baud=baud_rate)
        print("[INFO] Mavlink connection: Successful ")
    except Exception as e:
        print(f"[ERROR] Mavlink comm. failed: {e}")
        return

    while not stop_event.is_set():
        try:
            with socket.socket(socket.AF_INET, socket.SOCK_STREAM) as s:
                s.settimeout(10.0)  # Increased timeout for connection attempts
                print(f"[INFO] Attempting to connect to {target_ip}:{tcp_port}...")
                try:
                    s.connect((target_ip, tcp_port))
                    print("[INFO] TCP connected. Sending telemetry.")
                except socket.timeout:
                    print("[ERROR] Connection timed out. Retrying in 5 seconds...")
                    time.sleep(5)
                    continue
                except Exception as e:
                    print(f"[ERROR] Failed to connect: {e}. Retrying in 5 seconds...")
                    time.sleep(5)
                    continue

                while not stop_event.is_set():
                    try:
                        msg = master.recv_match(blocking=False)

                        if not msg:
                            time.sleep(0.1)
                            continue

                        msg_type = msg.get_type()
                        if msg_type == 'SYS_STATUS':
                            msg_data = msg.to_dict()

                            batV = msg_data.get('voltage_battery', 0) / 1000.0
                            batI = msg_data.get('current_battery', 0) / 100.0

                            telem_str = f"{batV:.2f} V {batI:.2f} A\n"
                            print(f"[Mavlink] {telem_str.strip()}")

                            try:
                                s.sendall(telem_str.encode("utf-8"))
                                print(f"Send: {telem_str.strip()}")
                            except Exception as e:
                                print(f"[ERROR] Telem. send error: {e}. Reconnecting...")
                                break  # Exit the inner loop to attempt reconnection

                        time.sleep(0.1)

                    except Exception as e:
                        print(f"[ERROR] Mavlink telemetry error: {e}. Reconnecting...")
                        break  # Exit the inner loop to attempt reconnection

        except KeyboardInterrupt:
            print("\n[INFO] Stopping Mavlink Telemetry.")
            break
        except Exception as e:
            print(f"[ERROR] Unexpected error: {e}. Retrying in 5 seconds...")
            time.sleep(5)

    print("[INFO] Mavlink telemetry thread exiting.")



if __name__ == "__main__":
    stop_event = threading.Event()

    # Initialize threads
    video_thread = threading.Thread(target=stream_video, args=(stop_event,), daemon=True)
    pwm_thread   = threading.Thread(target=update_channel, args=(stop_event,), daemon=True)
    telem_thread = threading.Thread(target=mavlink_telem, args=(stop_event,), daemon=True)

    # Start threads
    video_thread.start()
    pwm_thread.start()
    telem_thread.start()

    try:
        while True:
            time.sleep(1)
    except KeyboardInterrupt:
        print("\n[INFO] Exiting main program.")
        stop_event.set()
        pwm_thread.join()
        telem_thread.join()
        video_thread.join()
    finally:
        print("[INFO] Program terminated.")

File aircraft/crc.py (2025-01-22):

import sys

__author__ = "Nicco Kunzmann"
__version__ = "0.1.0"

PY2 = sys.version_info[0] == 2


class crc8(object):
    digest_size = 1
    block_size = 1

    _table = [0x00, 0xD5, 0x7F, 0xAA, 0xFE, 0x2B, 0x81, 0x54, 0x29, 0xFC, 0x56, 0x83, 0xD7, 0x02, 0xA8, 0x7D,
           0x52, 0x87, 0x2D, 0xF8, 0xAC, 0x79, 0xD3, 0x06, 0x7B, 0xAE, 0x04, 0xD1, 0x85, 0x50, 0xFA, 0x2F,
           0xA4, 0x71, 0xDB, 0x0E, 0x5A, 0x8F, 0x25, 0xF0, 0x8D, 0x58, 0xF2, 0x27, 0x73, 0xA6, 0x0C, 0xD9,
           0xF6, 0x23, 0x89, 0x5C, 0x08, 0xDD, 0x77, 0xA2, 0xDF, 0x0A, 0xA0, 0x75, 0x21, 0xF4, 0x5E, 0x8B,
           0x9D, 0x48, 0xE2, 0x37, 0x63, 0xB6, 0x1C, 0xC9, 0xB4, 0x61, 0xCB, 0x1E, 0x4A, 0x9F, 0x35, 0xE0,
           0xCF, 0x1A, 0xB0, 0x65, 0x31, 0xE4, 0x4E, 0x9B, 0xE6, 0x33, 0x99, 0x4C, 0x18, 0xCD, 0x67, 0xB2,
           0x39, 0xEC, 0x46, 0x93, 0xC7, 0x12, 0xB8, 0x6D, 0x10, 0xC5, 0x6F, 0xBA, 0xEE, 0x3B, 0x91, 0x44,
           0x6B, 0xBE, 0x14, 0xC1, 0x95, 0x40, 0xEA, 0x3F, 0x42, 0x97, 0x3D, 0xE8, 0xBC, 0x69, 0xC3, 0x16,
           0xEF, 0x3A, 0x90, 0x45, 0x11, 0xC4, 0x6E, 0xBB, 0xC6, 0x13, 0xB9, 0x6C, 0x38, 0xED, 0x47, 0x92,
           0xBD, 0x68, 0xC2, 0x17, 0x43, 0x96, 0x3C, 0xE9, 0x94, 0x41, 0xEB, 0x3E, 0x6A, 0xBF, 0x15, 0xC0,
           0x4B, 0x9E, 0x34, 0xE1, 0xB5, 0x60, 0xCA, 0x1F, 0x62, 0xB7, 0x1D, 0xC8, 0x9C, 0x49, 0xE3, 0x36,
           0x19, 0xCC, 0x66, 0xB3, 0xE7, 0x32, 0x98, 0x4D, 0x30, 0xE5, 0x4F, 0x9A, 0xCE, 0x1B, 0xB1, 0x64,
           0x72, 0xA7, 0x0D, 0xD8, 0x8C, 0x59, 0xF3, 0x26, 0x5B, 0x8E, 0x24, 0xF1, 0xA5, 0x70, 0xDA, 0x0F,
           0x20, 0xF5, 0x5F, 0x8A, 0xDE, 0x0B, 0xA1, 0x74, 0x09, 0xDC, 0x76, 0xA3, 0xF7, 0x22, 0x88, 0x5D,
           0xD6, 0x03, 0xA9, 0x7C, 0x28, 0xFD, 0x57, 0x82, 0xFF, 0x2A, 0x80, 0x55, 0x01, 0xD4, 0x7E, 0xAB,
           0x84, 0x51, 0xFB, 0x2E, 0x7A, 0xAF, 0x05, 0xD0, 0xAD, 0x78, 0xD2, 0x07, 0x53, 0x86, 0x2C, 0xF9]

    def __init__(self, initial_string=b'', initial_start=0x00):
        """Create a new crc8 hash instance."""
        self._sum = initial_start
        self._update(initial_string)

    def update(self, bytes_):
        """Update the hash object with the string arg.
        Repeated calls are equivalent to a single call with the concatenation
        of all the arguments: m.update(a); m.update(b) is equivalent
        to m.update(a+b).
        """
        self._update(bytes_)

    def digest(self):
        """Return the digest of the bytes passed to the update() method so far.
        This is a string of digest_size bytes which may contain non-ASCII
        characters, including null bytes.
        """
        return self._digest()

    def hexdigest(self):
        """Return digest() as hexadecimal string.
        Like digest() except the digest is returned as a string of double
        length, containing only hexadecimal digits. This may be used to
        exchange the value safely in email or other non-binary environments.
        """
        return hex(self._sum)[2:].zfill(2)

    if PY2:
        def _update(self, bytes_):
            if isinstance(bytes_, unicode):
                bytes_ = bytes_.encode()
            elif not isinstance(bytes_, str):
                raise TypeError("must be string or buffer")
            table = self._table
            _sum = self._sum
            for byte in bytes_:
                _sum = table[_sum ^ ord(byte)]
            self._sum = _sum

        def _digest(self):
            return chr(self._sum)
    else:
        def _update(self, bytes_):
            if isinstance(bytes_, str):
                raise TypeError("Unicode-objects must be encoded before"\
                                " hashing")
            elif not isinstance(bytes_, (bytes, bytearray)):
                raise TypeError("object supporting the buffer API required")
            table = self._table
            _sum = self._sum
            for byte in bytes_:
                _sum = table[_sum ^ byte]
            self._sum = _sum

        def _digest(self):
            return bytes([self._sum])

    def copy(self):
        """Return a copy ("clone") of the hash object.

        This can be used to efficiently compute the digests of strings that
        share a common initial substring.
        """
        crc = crc8()
        crc._sum = self._sum
        return crc


__all__ = ['crc8']

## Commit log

2025-01-26 added schematic PCB
    [CM5IO.kicad_pcb, CM5IO.kicad_sch, CM5_GPIO.kicad_sch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]
2025-02-03 pre-check schematic layout
    [SKQGAFE010.step, SM04B-SRSS-TB_LF__SN_.step, SM06B-SRSS-TB_LF__SN_.step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]
2025-02-09 added PCIe to PCBA
    [specter.kicad_pcb, specter.kicad_sch]
2025-02-09 added PCIe slot
    [specter.kicad_pcb, specter.kicad_sch]
2025-02-11 started PCB layout
    [specter.kicad_pcb, specter.kicad_sch]
2025-02-13 updated PCB layout
    [specter.kicad_pcb]
2025-02-16 started PCB traces
    [specter.kicad_pcb]
2025-02-21 impedance matching
    [specter.kicad_pcb]
2025-03-11 updated PCB
    [specter.kicad_pcb]
2025-03-14 added SD card routing
    [specter.kicad_pcb]
2025-03-17 GPIO wired
    [specter.kicad_pcb, specter.kicad_sch]
2025-03-18 finalised routing on PCB
    [specter.kicad_pcb]
2025-03-25 small PCB updates
    [specter.kicad_pcb]
2025-03-25 power lanes PCB
2025-03-25 added power planes
    [specter.kicad_pcb, specter.kicad_sch]
2025-03-26 finished PCB first round
2025-03-26 added last minute changes
    [specter.kicad_pcb]
2025-04-13 refined PCB
    [specter.kicad_pcb, specter.kicad_sch]
2025-04-13 finishing touches
    [specter.kicad_pcb, specter.kicad_sch]
2025-04-15 added 3D models
    [SM04B-SRSS-TB(LF)(SN)--3DModel-STEP-269445.STEP, specter.kicad_pcb]
2025-05-07 final PCB changes
    [BOM-specter.csv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]
2025-05-20 added JLC options
    [specter.kicad_pcb]

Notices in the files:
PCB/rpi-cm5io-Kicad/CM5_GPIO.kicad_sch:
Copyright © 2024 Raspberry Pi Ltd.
